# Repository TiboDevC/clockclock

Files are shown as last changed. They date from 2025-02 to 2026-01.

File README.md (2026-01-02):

# ClockClock - 48 Stepper Motors Kinetic Clock

Personal project of a kinetic clock inspired by [Humans Since 1982](https://www.humanssince1982.com/), using 48 stepper
motors to display time in an artistic and dynamic way.

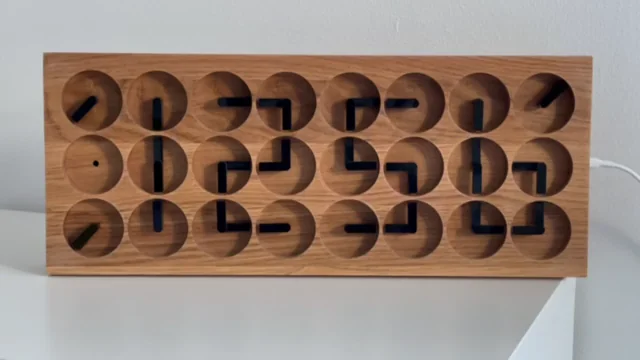
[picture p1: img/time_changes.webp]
Clock front


## Table of Contents

- [Project Overview](#project-overview)
- [Technical Architecture](#technical-architecture)
- [Hardware](#hardware)
- [Firmware](#firmware)
- [Build and Flash](#build-and-flash)
- [Configuration](#configuration)
- [Schematics and Documentation](#schematics-and-documentation)

---

## Project Overview

### Goals

This project aims to create a kinetic clock with the following constraints:

1. **Simplicity**: Use a single microcontroller (ESP32-C3) to control all 48 motors, unlike similar projects that use
   multiple MCUs
2. **Time Accuracy**: Always accurate clock without permanent internet connection thanks to DCF77 receiver
3. **Compact Size**: Target dimensions around 100 cm length
4. **Cost-Effective**: Reasonable budget using BKA30D-R5 motors at ~4€/piece

### Specifications

- **48 stepper motors** individually controlled
- **Display**: 4 digits (HH:MM) with 12 motors per digit
- **Angular Resolution**: 4320 steps/revolution (12 steps/degree)
- **Power Consumption**: ~960 mA @ 5V (20mA/motor)
- **Time Synchronization**: DCF77 (European long-range radio signal)

---

## Technical Architecture

### Overview

The ClockClock architecture is built around a highly efficient, centralized control system that manages all 48 stepper
motors from a single ESP32-C3 microcontroller. This approach contrasts with typical multi-motor projects that require
multiple microcontrollers or complex distributed systems.

#### Control Chain

```
ESP32-C3 → TPIC6C595 Shift Registers (×12) → VID6606 Motor Drivers (×12) → BKA30D-R5 Motors (×48)
   ↓                    ↓                              ↓                           ↓
 3 GPIO              96 bits                    2 signals per motor         2 bits per motor
  pins            (SPI @ 10MHz)                  (STEP + DIR)              (individual control)
```

#### Key Design Principles

1. **Minimal GPIO Usage**: The entire system uses only 3 GPIO pins (MOSI, SCK, SS) thanks to the shift register cascade.
   This leaves the ESP32-C3's remaining pins available for other peripherals (I2C for RTC, buttons, encoder, etc.).

2. **Serial-to-Parallel Conversion**: The 12 cascaded TPIC6C595 shift registers convert the serial SPI data stream into
   96 parallel outputs. Each motor requires 2 control bits (STEP and DIR), allowing precise control of all 48 motors
   simultaneously.

3. **Hierarchical Organization**:
    - **1 ESP32-C3**: Single point of control and decision-making
    - **12 Shift Registers**: Each controlling 4 motors (8 bits per register)
    - **12 VID6606 Drivers**: Each driving 4 motors independently
    - **48 Motors**: Organized in 4 groups of 12 (one per digit displayed)

4. **Data Flow Pipeline**:
   ```
   Time/Animation Logic → Motor Position Calculation → SPI Data Preparation → 
   Hardware SPI Transfer (10µs) → Parallel Latch → Simultaneous Motor Update
   ```

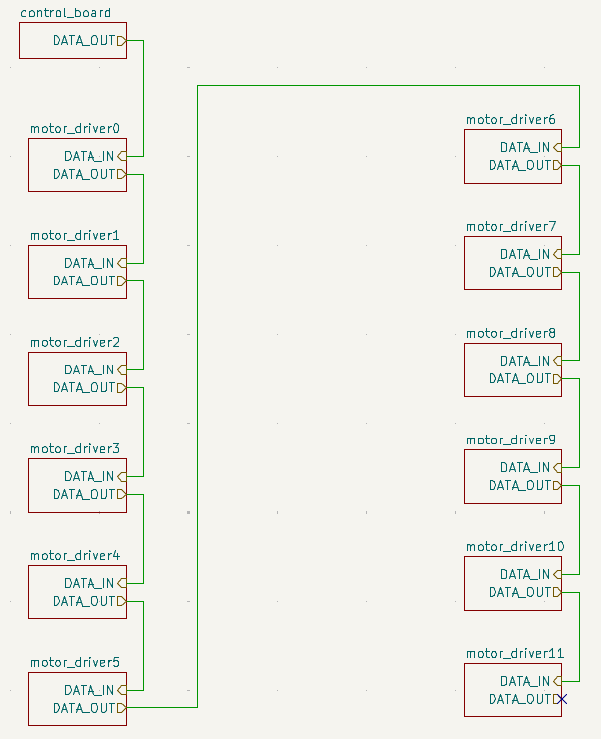
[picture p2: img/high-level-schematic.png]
High Level Schematic

*All motor blocks are linked together*

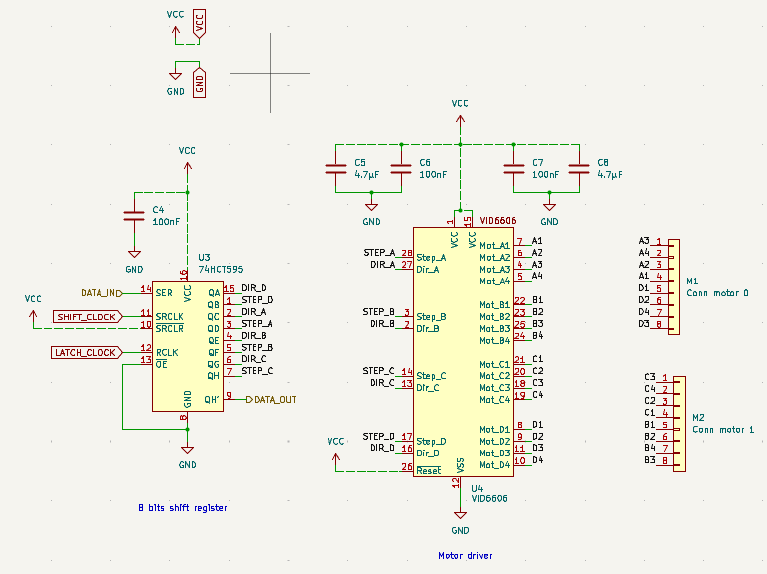
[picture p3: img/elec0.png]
Electronic Architecture

*A motor block*

### Motor Control

#### BKA30D-R5 Stepper Motors

Features:

- **Type**: Bipolar stepper motor
- **Current**: 20 mA per motor
- **Resolution**: 360° continuous rotation
- **Torque**: Suitable for lightweight hands (acrylic)

<p>
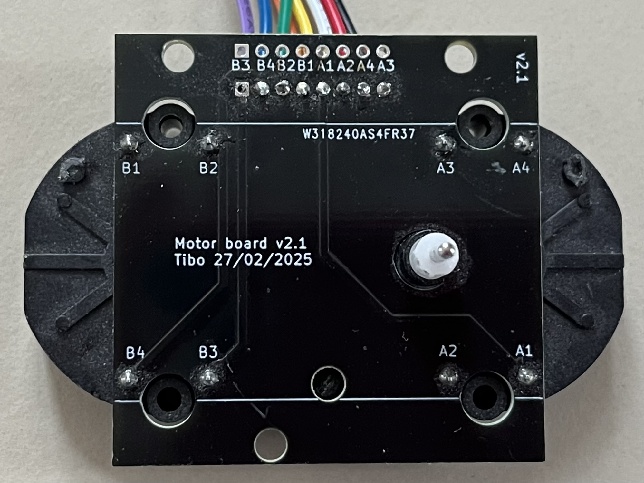
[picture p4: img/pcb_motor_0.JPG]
Motor
  
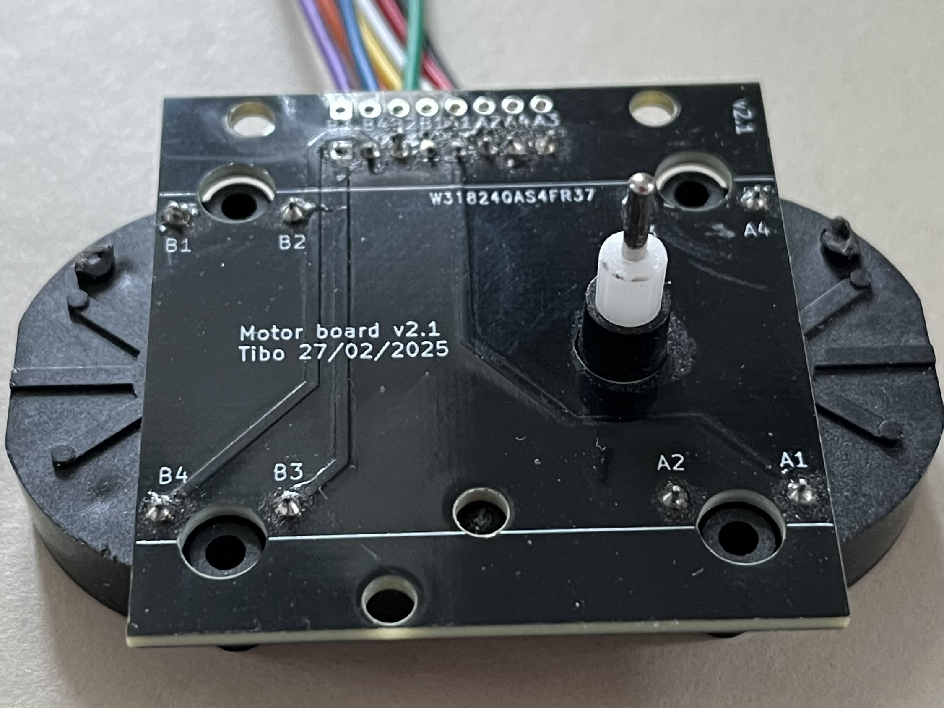
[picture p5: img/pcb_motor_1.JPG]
Motor
  

<em>The motor itself with its PCB to connect to the motor driver</em>
</p>

#### VID6606 Drivers

Each VID6606 driver (or equivalent AX1201728SG/STI6606z) can control **4 motors** with only 2 signals per motor:

- **STEP**: Step signal (rising edge = one step)
- **DIR**: Direction (HIGH/LOW)

<p>
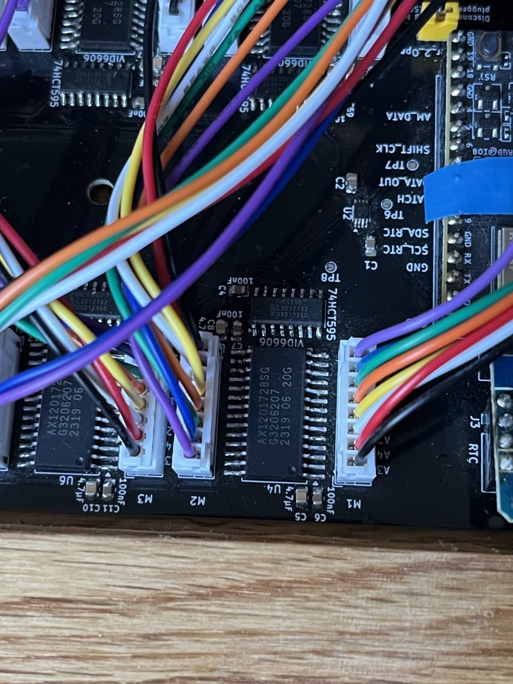
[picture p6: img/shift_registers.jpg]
  

<em>The AX1201728SG driver is connected to 4 motors (the two connectors on its right and left). On top, the shift
register</em>
</p>

#### TPIC6C595 Shift Registers

- **Quantity**: 12 x 8-bit registers in cascade
- **Total**: 96 bits of control for 48 motors (2 bits/motor)
- **Communication**: Hardware SPI interface from ESP32-C3
- **Clock Speed**: 10 MHz
- **Data Transfer**: 12 bytes (96 bits) in approximately 10 µs
- **Signals**:
    - **MOSI** (Data Out): Serial data to first register
    - **SCK** (Shift Clock): Shift clock at 10 MHz
    - **SS** (Latch Clock): Synchronous output latch

**Key Advantages**:

1. **Hardware SPI Optimization**: Using the ESP32-C3's hardware SPI peripheral instead of bit-banging provides
   significant performance improvement. The 10 MHz clock allows extremely fast data transfer of all 12 bytes in
   approximately 10 microseconds.
2. **Perfect Synchronization**: The latch mechanism ensures all 48 motors receive their new commands simultaneously in a
   single atomic operation. There is no timing skew between motors - they all update at exactly the same moment when the
   latch signal is triggered.
3. **Monolithic Control**: This architecture provides a single point of control with zero concurrency issues. All motor
   states are managed centrally by the ESP32-C3, eliminating the complexity and synchronization challenges found in
   distributed control systems using multiple microcontrollers.
4. **Deterministic Timing**: The fast SPI transfer combined with the synchronous latch ensures predictable, jitter-free
   motor updates, critical for smooth visual animations.

### Time Synchronization

#### DS3231 RTC Module

- **Accuracy**: ±2 ppm (±1 minute/year)
- **Interface**: I2C
- **Battery**: CR2032 backup for timekeeping

#### DCF77 Receiver

- **Module**: CANADUINO DCF77 Radio Clock Receiver Kit V2
- **Frequency**: 77.5 kHz (transmitter in Mainflingen, Germany)
- **Range**: ~2000 km in optimal conditions
- **Accuracy**: Atomic clock synchronization
- **Function**: Automatic DS3231 recalibration

#### DST (Daylight Saving Time) Management

The firmware implements European rules:

- **Summer Time Start**: Last Sunday of March at 2:00 → 3:00 (UTC+2)
- **Winter Time Start**: Last Sunday of October at 3:00 → 2:00 (UTC+1)
- **Automatic Calculation**: Zeller's algorithm to determine Sundays

---

## Hardware

### Main Board

**Files**: `elec/clockclock_main/` → [PDF Schematic](elec/clockclock_main/output/clockclock_main.pdf)

<p>
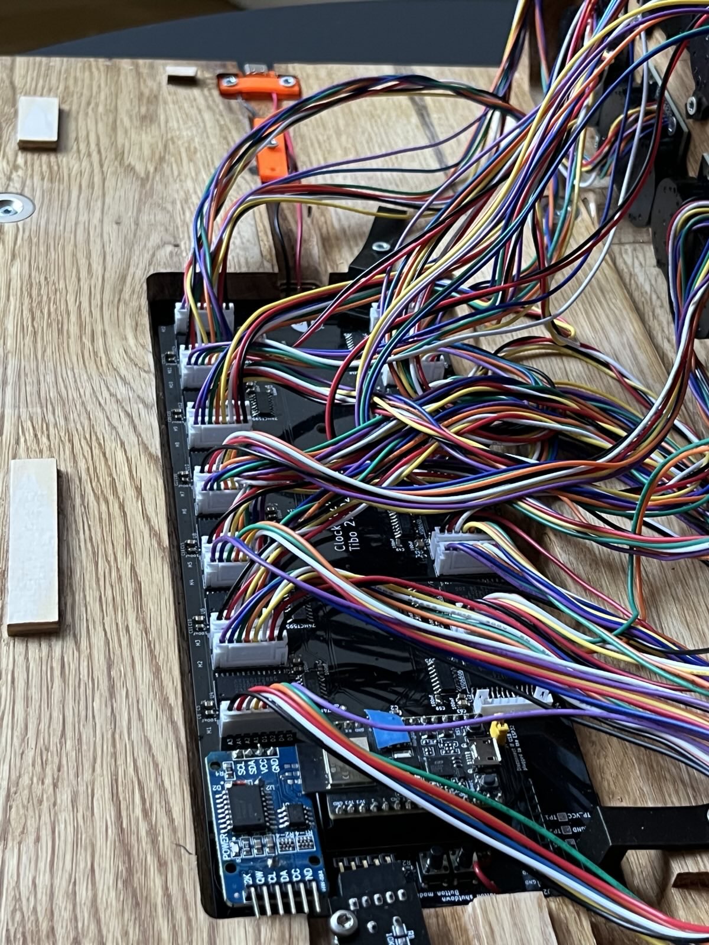
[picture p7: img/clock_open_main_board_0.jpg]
Main board
  
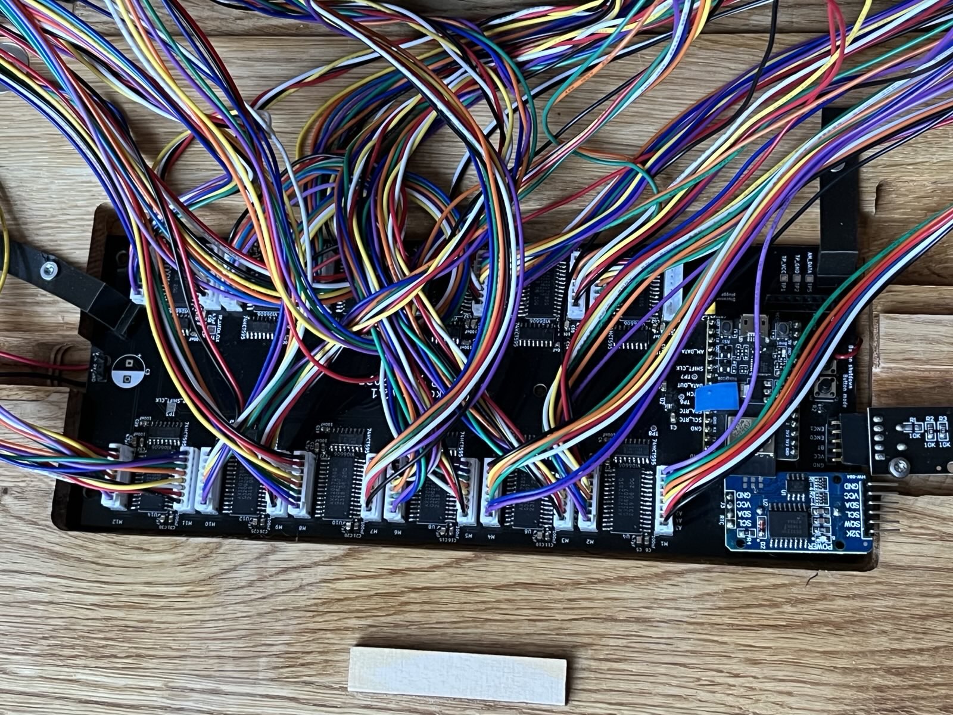
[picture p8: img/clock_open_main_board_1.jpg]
Main board
  

<em>Main board fully wired</em>
</p>

<p>
  Clock starts

<em>Clock starts</em>
</p>

#### Main Components

| Component | Reference | Quantity | Function |
|---|---|---|---|
| Microcontroller | ESP32-C3-DevKitM-1 | 1 | Central control (RISC-V) |
| Shift Registers | TPIC6C595 | 12 | Output expansion |
| Motor Drivers | VID6606 / AX1201728SG | 12 | 4 motors per driver |
| RTC | DS3231 | 1 | Real-time clock |
| Radio Receiver  | DCF77 CANADUINO | 1 | Atomic sync |

#### User Interface

**Buttons**:

- **PIN 0**: Rotary encoder button
- **PIN 1**: Mode (short = config, long = calibration)
- **PIN 10**: Shutdown (long press)

**Rotary Encoder**:

- **PIN 2**: Encoder A (interrupt)
- **PIN 3**: Encoder B (interrupt)

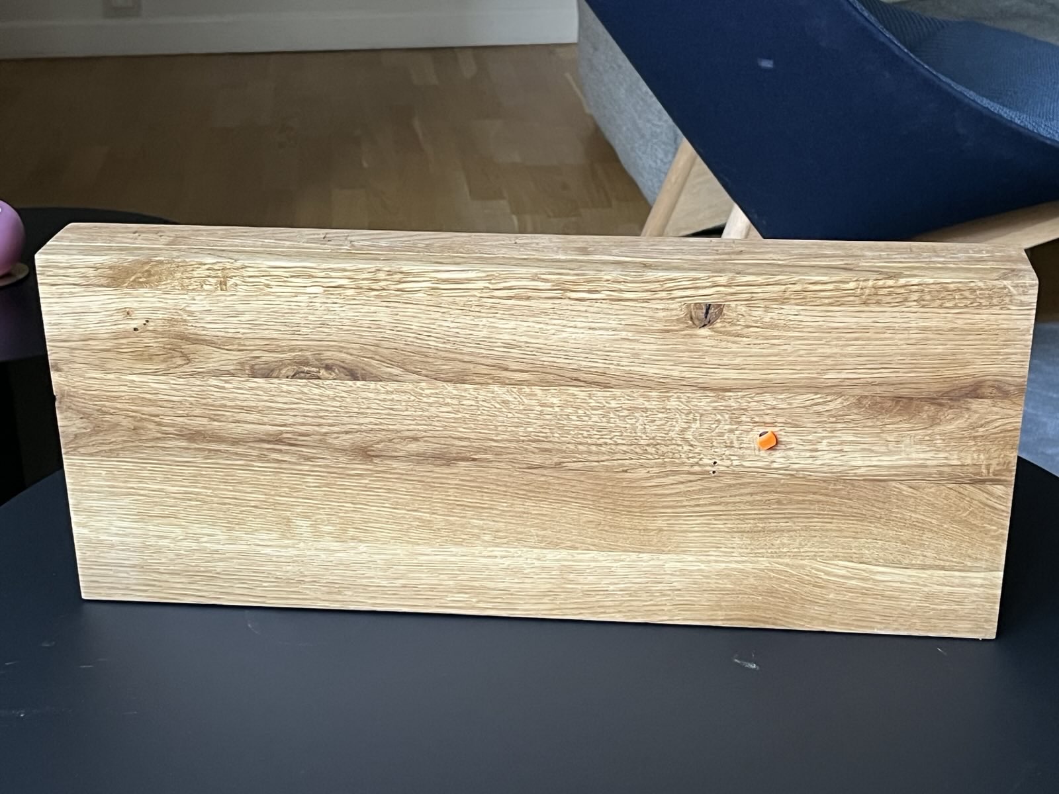
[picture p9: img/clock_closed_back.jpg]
Back of the clock

*Only one button is connected (the orange button here), and it is used to enter the "shutdown" mode*

### Motor Boards

**Files**: `elec/clokclock_stepper/` → [PDF Schematic](elec/clokclock_stepper/output/clokclock_stepper.pdf)

Each board is very simple and connects a BKA30D-R5 motor to its VID6606 driver.

**Total**: 24 identical motor boards

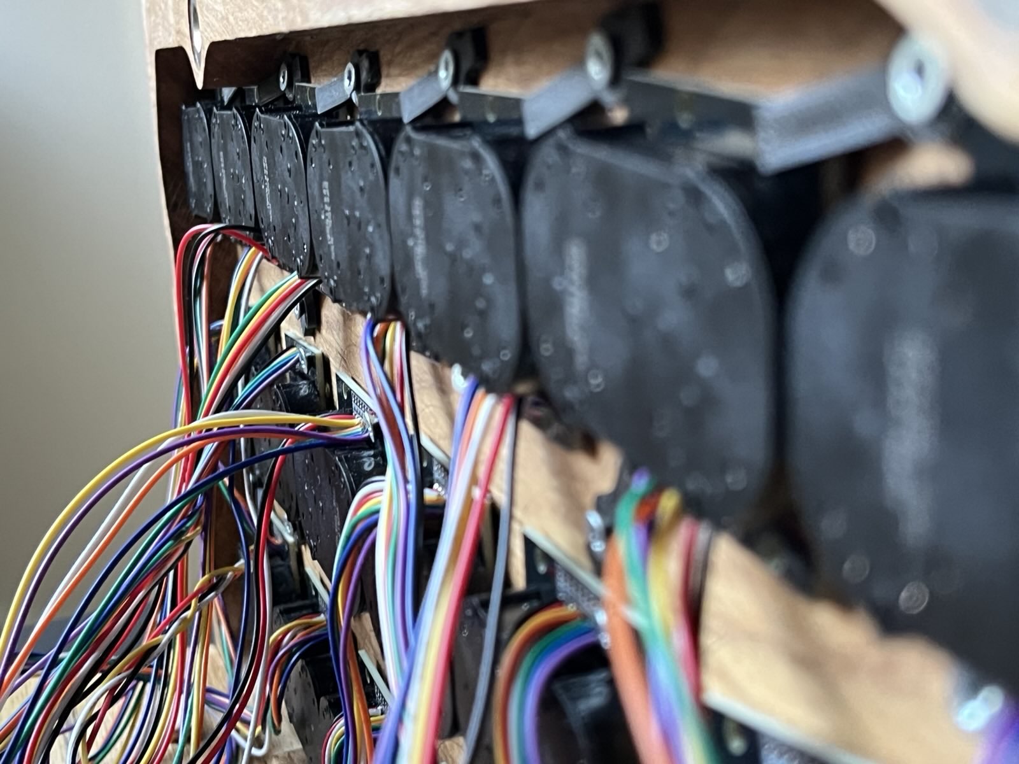
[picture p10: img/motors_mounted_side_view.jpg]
Motors mounted

*Row of motors mounted on the main frame*

### Power Supply

- **Source**: Standard USB-C charger
- **Voltage**: 5V DC
- **Current**: Minimum 1.5A recommended
- **Regulation**: Integrated on ESP32-C3-DevKitM-1 (3.3V logic)

### Hands

This is the part that took most of the design time!
I tried many different materials and manufacturing methods before settling on laser-cut acrylic hands.

The challenge is to be able to manufacture hands that can be unmounted/remounted easily and that fit perfectly on the
motor shaft.  
In addition, the hands should be as close together as possible in order to maintain a good viewing angle when looking at
the clock from the side.

<p>
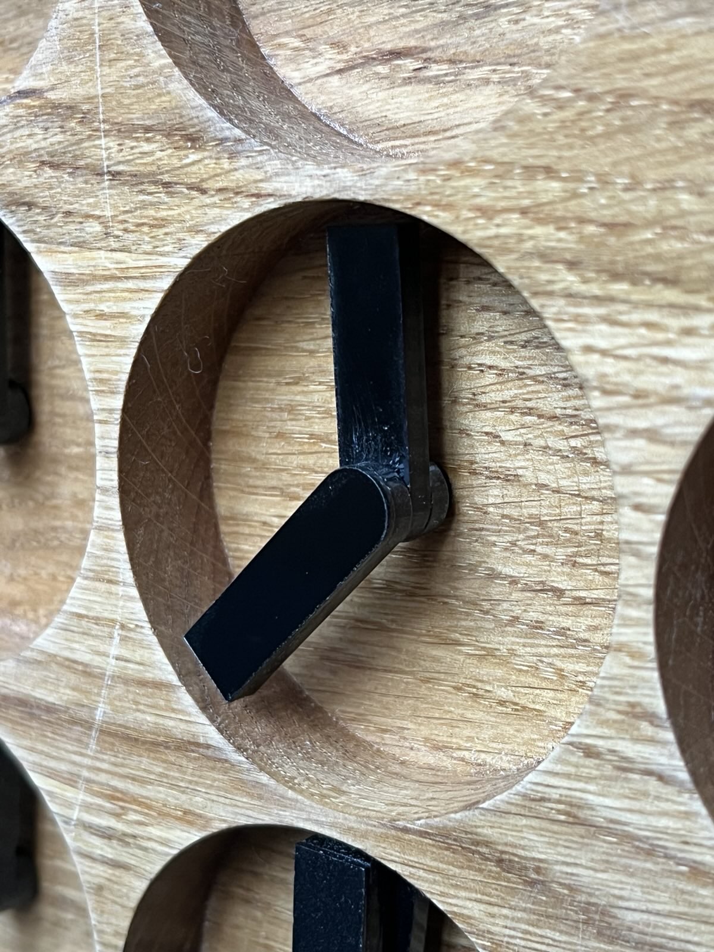
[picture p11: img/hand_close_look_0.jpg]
Hand
  
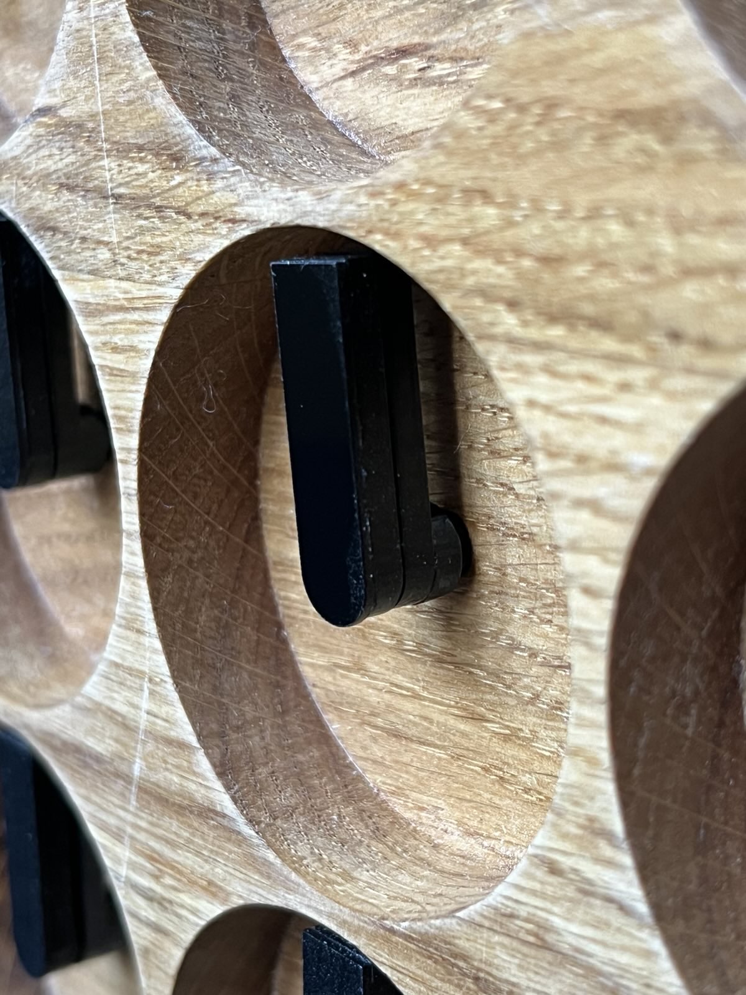
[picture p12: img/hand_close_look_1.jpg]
Hand
  

<em>Mounted hands</em>
</p>

Here is the final solution I adopted:
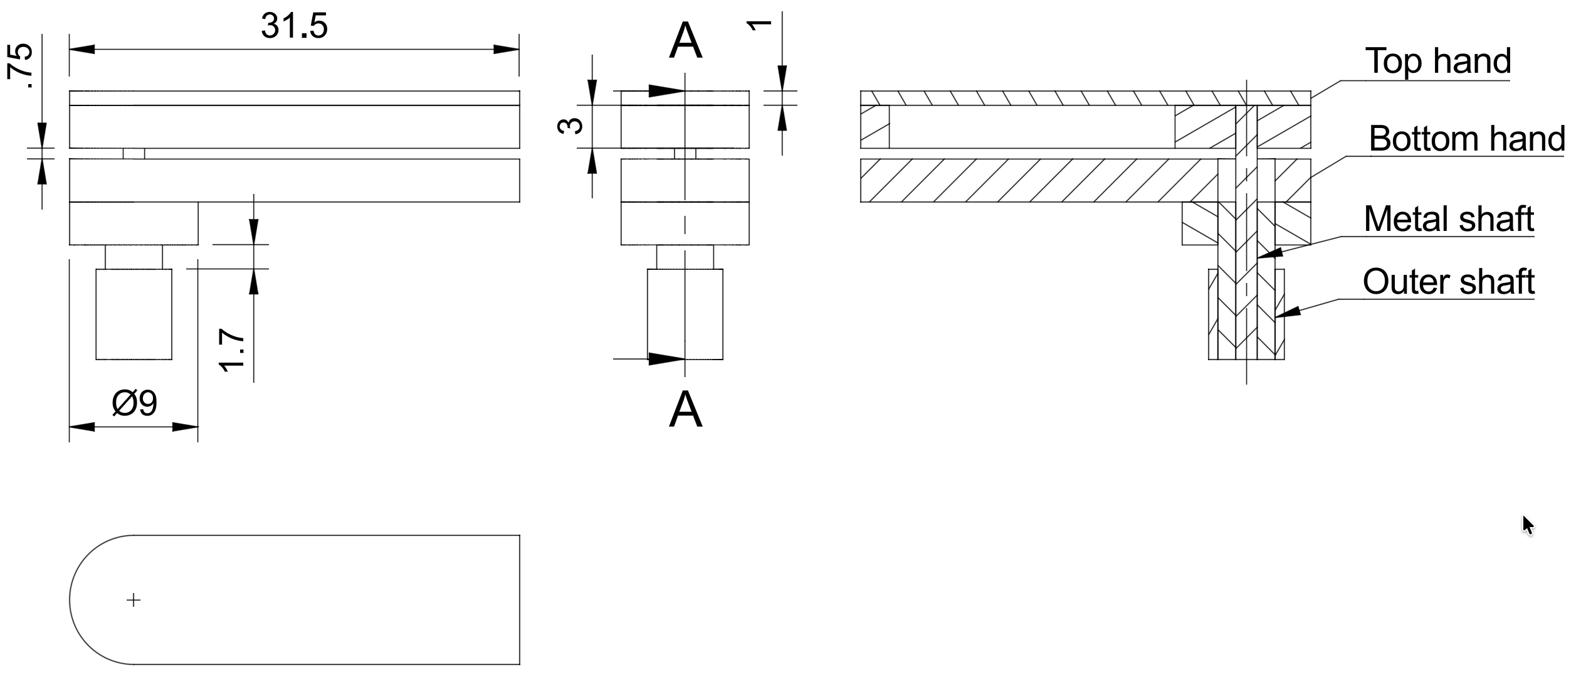
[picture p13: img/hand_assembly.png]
Hands assembly

*Hands assembly*

Both the top and bottom hands are in two acrylic parts glued together.  
The top one as a 1mm acrylic part glued to a 3mm part that fits on the motor shaft.  
The bottom one is a 3mm part glued to a 3mm part that fits on the motor shaft.

---

## Firmware

### Development Environment

- **Framework**: Arduino (PlatformIO)
- **Platform**: Espressif32
- **Language**: C++20 (GNU++2a)
- **IDE**: VSCode + PlatformIO recommended

### Code Structure

```
firmware/
├── platformio.ini          # Project configuration
├── include/
│   └── cfg.hpp            # Global constants (motors count, pins, etc.)
└── src/
    ├── main.cpp           # Entry point
    ├── time_manager.*     # Time management and DST
    ├── ntp_sync.*         # Optional NTP sync (dev only)
    ├── animation/         # Animation system
    │   ├── animation_manager.*
    │   ├── wave_animation.*
    │   └── sync_rotation_animation.*
    ├── button/            # Button and encoder handling
    │   └── button.*
    ├── mode/              # Operating modes
    │   ├── mode.*
    │   ├── calibration.*
    │   └── cfg_time.*
    └── motor/             # Motor control
        ├── motor_motion.* # Mapping and sequences
        ├── motion.*       # Display logic
        ├── shift_register.* # SPI interface
        └── AccelStepper.* # Movement library
```

### Operating Modes

The firmware implements several operation modes:

#### 1. MODE_CLOCK_DISPLAY (default)

- Display current time
- Update every minute
- Execute scheduled animations
- Sync with RTC every 500ms

#### 2. MODE_CLOCK_CONFIG

- Manual time configuration
- Navigation with rotary encoder
- Button validation
- 20s timeout → return to display

#### 3. MODE_CALIB (calibration)

- Access: long press MODE button
- Function: Reset zero position of all motors
- Sequence: rotation to reference position, manual validation, save new origin

#### 4. MODE_SHUTDOWN

- Access: long press SHUTDOWN button
- All motors return to neutral position (0°)
- Power saving mode

### Animation System

The `AnimationManager` enables choreographed animations:

**Available Animations**:

1. **Wave Animation**: Undulating wave across all motors
2. **Sync Rotation**: Synchronized rotation of all motors
3. **Custom**: Possibility to implement new animations

**Triggering**:

- **Scheduled**: At specific times (e.g., every hour)
- **Manual**: Via user interface
- **Transition**: Between digit changes

### Libraries

PlatformIO dependencies:

- `NorthernWidget/DS3231@1.1.2`: RTC interface
- `arduino-libraries/NTPClient@^3.2.1`: Optional NTP sync

---

## Build and Flash

### Prerequisites

```bash
# Install PlatformIO CLI
pip install platformio

# Or via VSCode: Install "PlatformIO IDE" extension
```

### Build

```bash
cd firmware/
pio run
```

### Upload to ESP32-C3

```bash
# Via USB
pio run --target upload

# Serial monitor
pio device monitor
```

### WiFi Configuration (Optional)

To enable NTP sync during development, enable `NTP_WIFI_SYNC` define in `main.cpp` and configure your WiFi credentials.

Note: In production, WiFi is not required thanks to the DCF77 module.

---

## Configuration

### Motor Parameters

Motor speed and acceleration can be adjusted in `firmware/src/motor/motor_motion.cpp`.

### Timezone Configuration

The firmware is configured for Central European Time (CET/CEST) by default. To change timezone, modify the DST
configuration in `main.cpp`.

### Initial Calibration

1. Power on the device
2. **Long press** MODE button → Calibration mode
3. Verify physical alignment of hands
4. Validate with encoder button
5. System saves new zero reference

---

## Schematics and Documentation

### Electronic Design Files

| Document | Path | Format |
|---|---|---|
| Main board schematic  | [`elec/clockclock_main/output/clockclock_main.pdf`](elec/clockclock_main/output/clockclock_main.pdf) | PDF |
| Main board PCB | `elec/clockclock_main/clockclock_main.kicad_pcb` | KiCad  |
| Motor board schematic | [`elec/clokclock_stepper/output/clokclock_stepper.pdf`](elec/clokclock_stepper/output/clokclock_stepper.pdf) | PDF |
| Motor board PCB | `elec/clokclock_stepper/clokclock_stepper.kicad_pcb` | KiCad  |
| Driver test board | `elec/test_board_motor_driver/` | KiCad  |

### Datasheets

All datasheets are available in the [`datasheet/`](datasheet/) folder:

- **Motor**: [BKA30D-R5.webp](datasheet/BKA30D-R5.webp)
- **Driver**: [VID28 user manual](datasheet/VID28%20user%20manual-1.pdf)
- **DCF77**: [CANADUINO_Atomic_Clock_Receiver_Kit_V2.pdf](datasheet/CANADUINO_Atomic_Clock_Receiver_Kit_V2.pdf)

---

## Development Notes

### Debug

The code includes conditional debug flags that can be enabled in respective source files:

- `DEBUG` - General messages
- `DEBUG_MOTION` - Motor control debug
- `DEBUG_TIME_MGMT` - Time management debug
- `DEBUG_ANIMATION` - Animation debug
- `DEBUG_MODE` - Mode debug

### Pre-commit Hooks

Git pre-commit configuration available: `.pre-commit-config.yaml`

```bash
pip install -r requirements.txt
pre-commit install
```

---

## License

This project is open-source. Free to use and modify.

## Acknowledgments

Inspired by the artistic work of [Humans Since 1982](https://www.humanssince1982.com/).

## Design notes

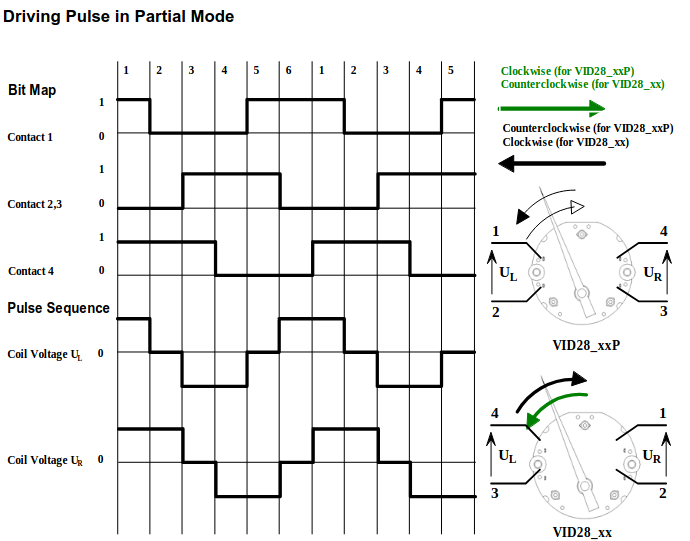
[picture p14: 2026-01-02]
img/BKA30D-R5_sequence.png

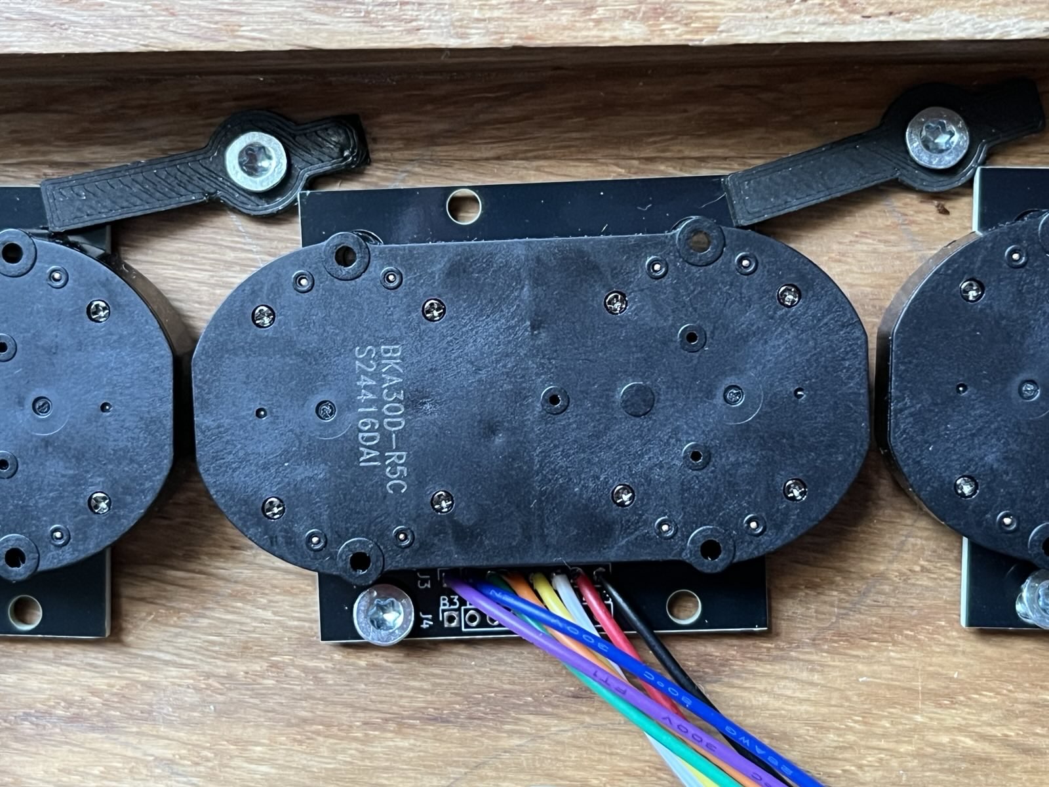
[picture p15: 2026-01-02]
img/motor_mounted.jpg

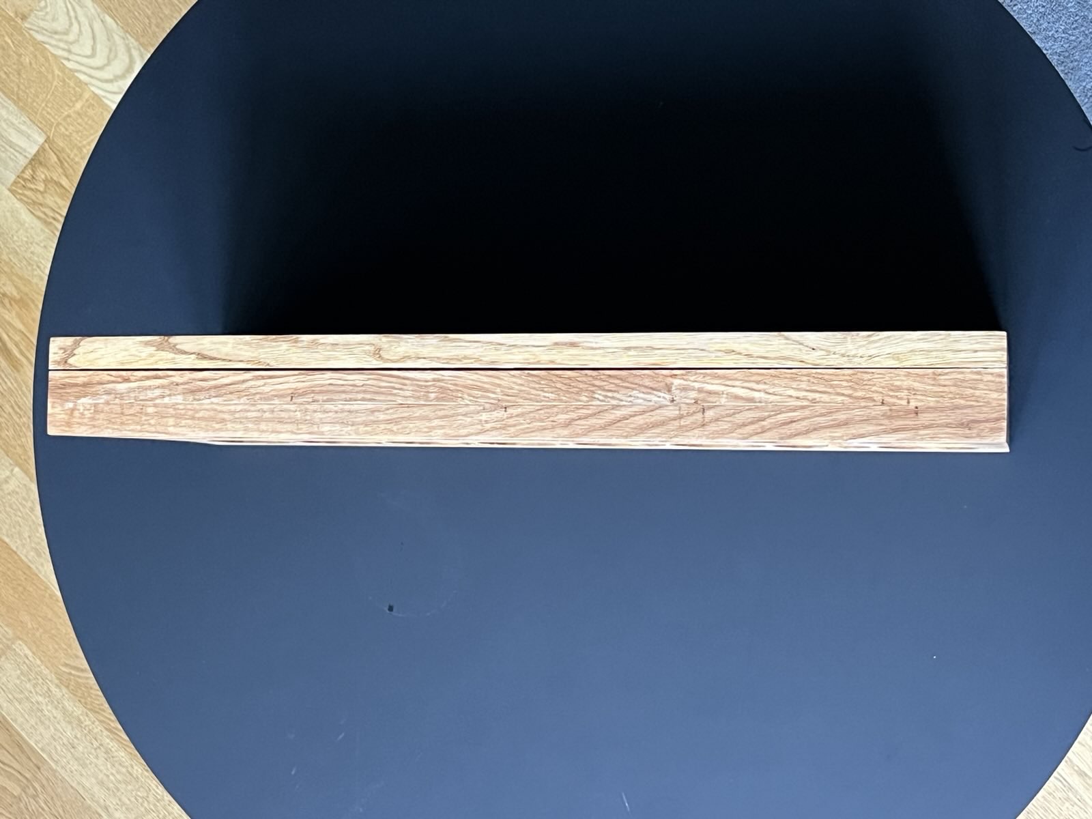
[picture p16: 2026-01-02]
img/clock_closed_top.jpg

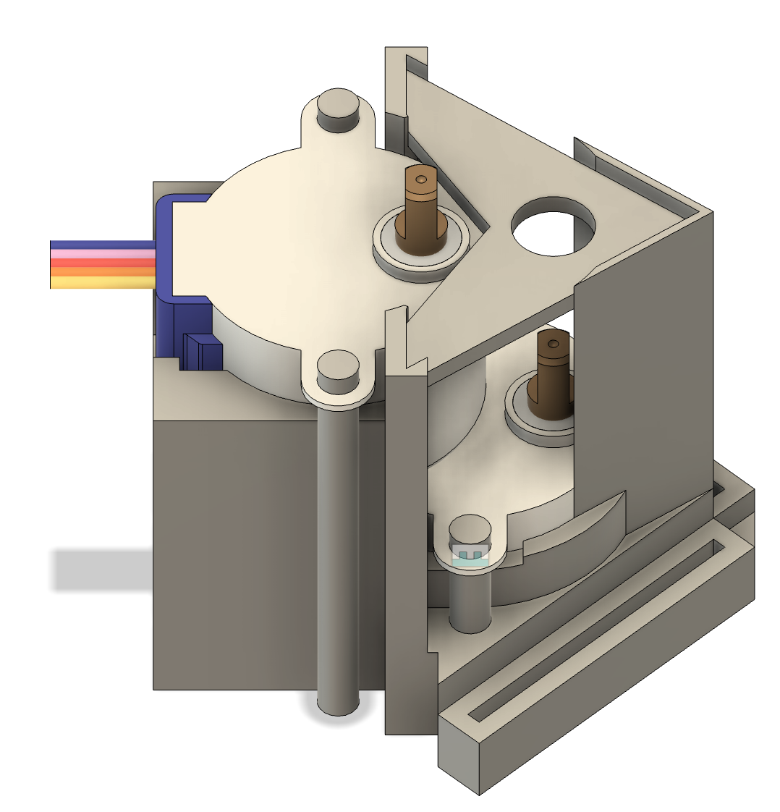
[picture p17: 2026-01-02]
img/motor00000.png

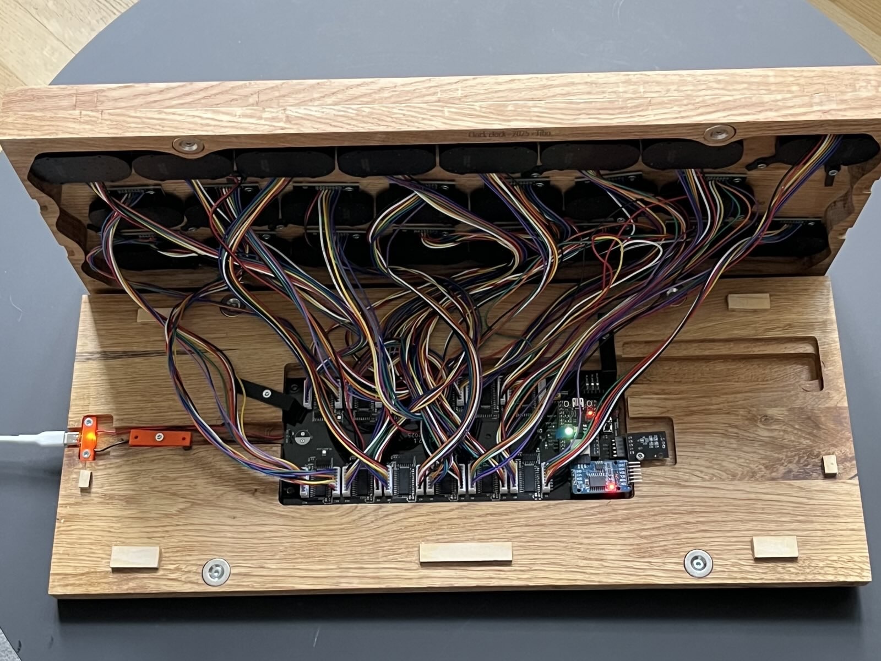
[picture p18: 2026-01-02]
img/clock_open_back.jpg

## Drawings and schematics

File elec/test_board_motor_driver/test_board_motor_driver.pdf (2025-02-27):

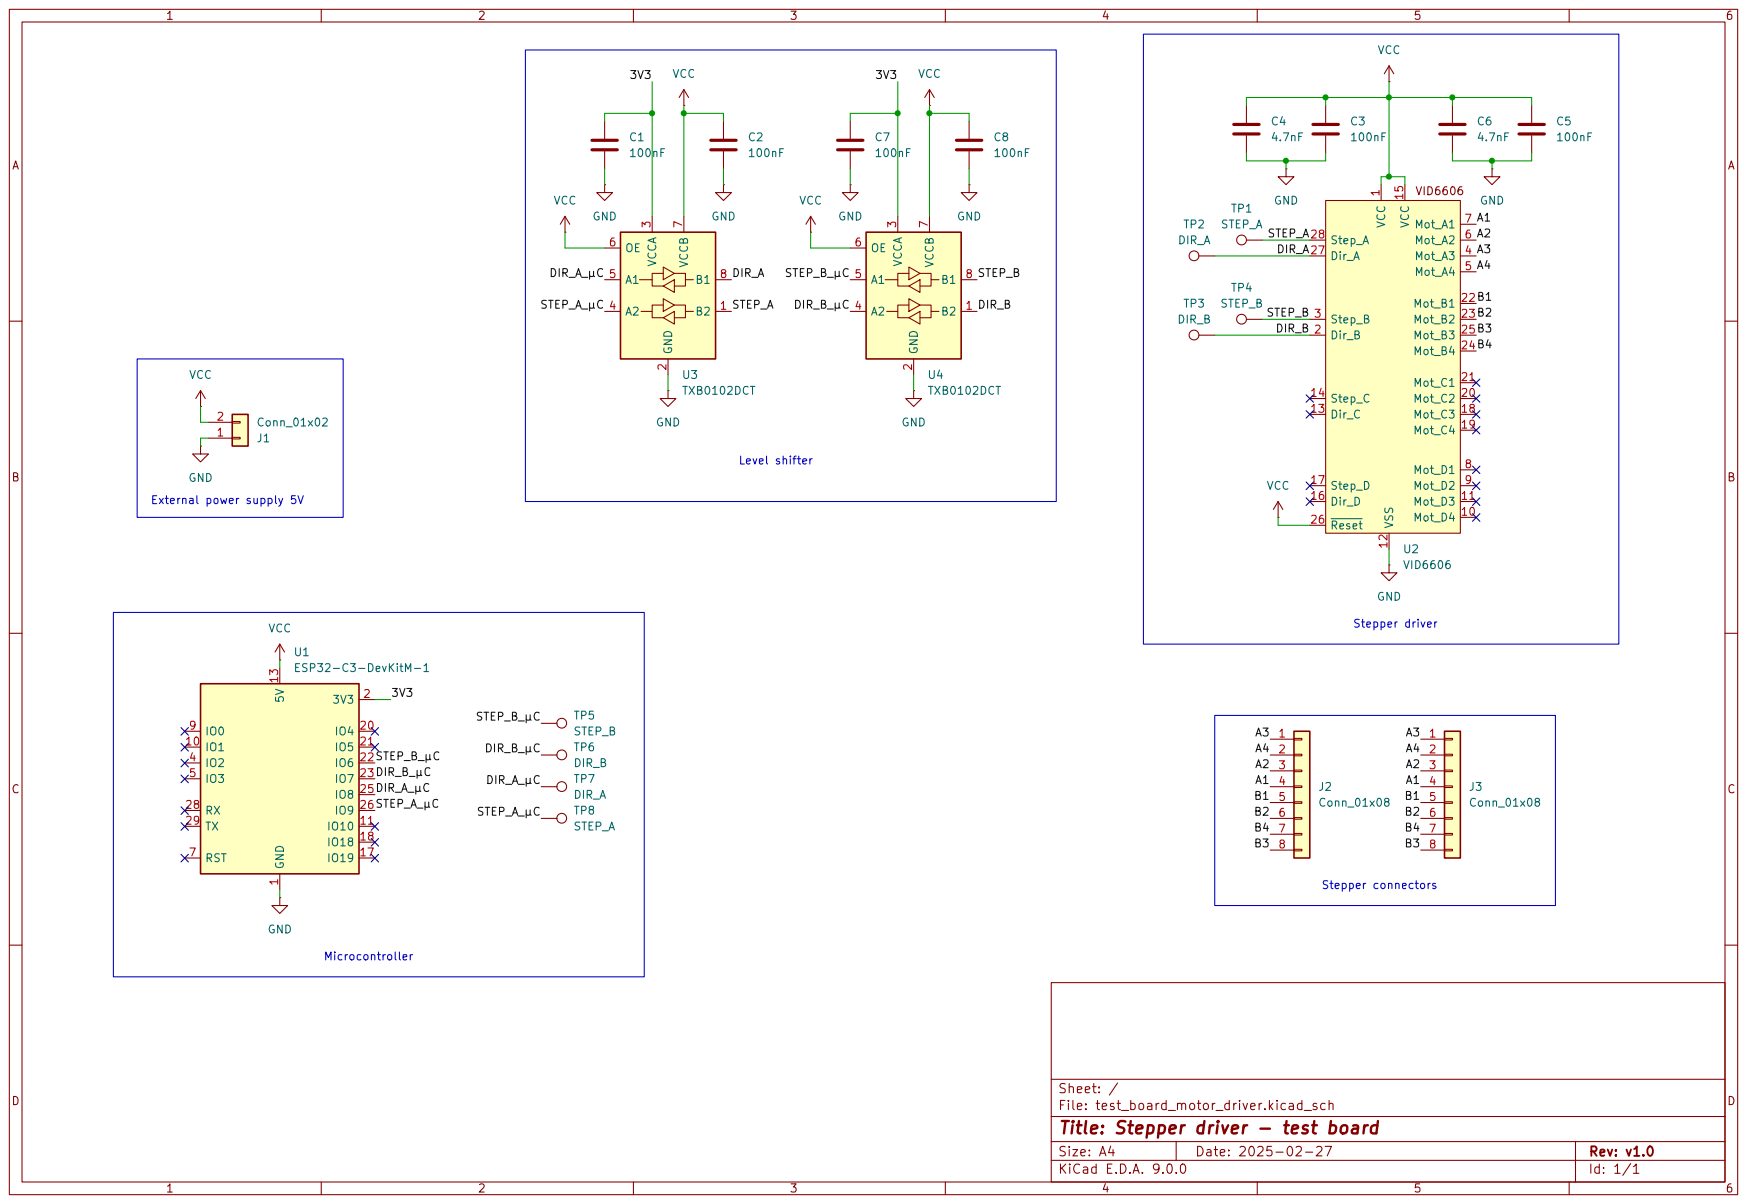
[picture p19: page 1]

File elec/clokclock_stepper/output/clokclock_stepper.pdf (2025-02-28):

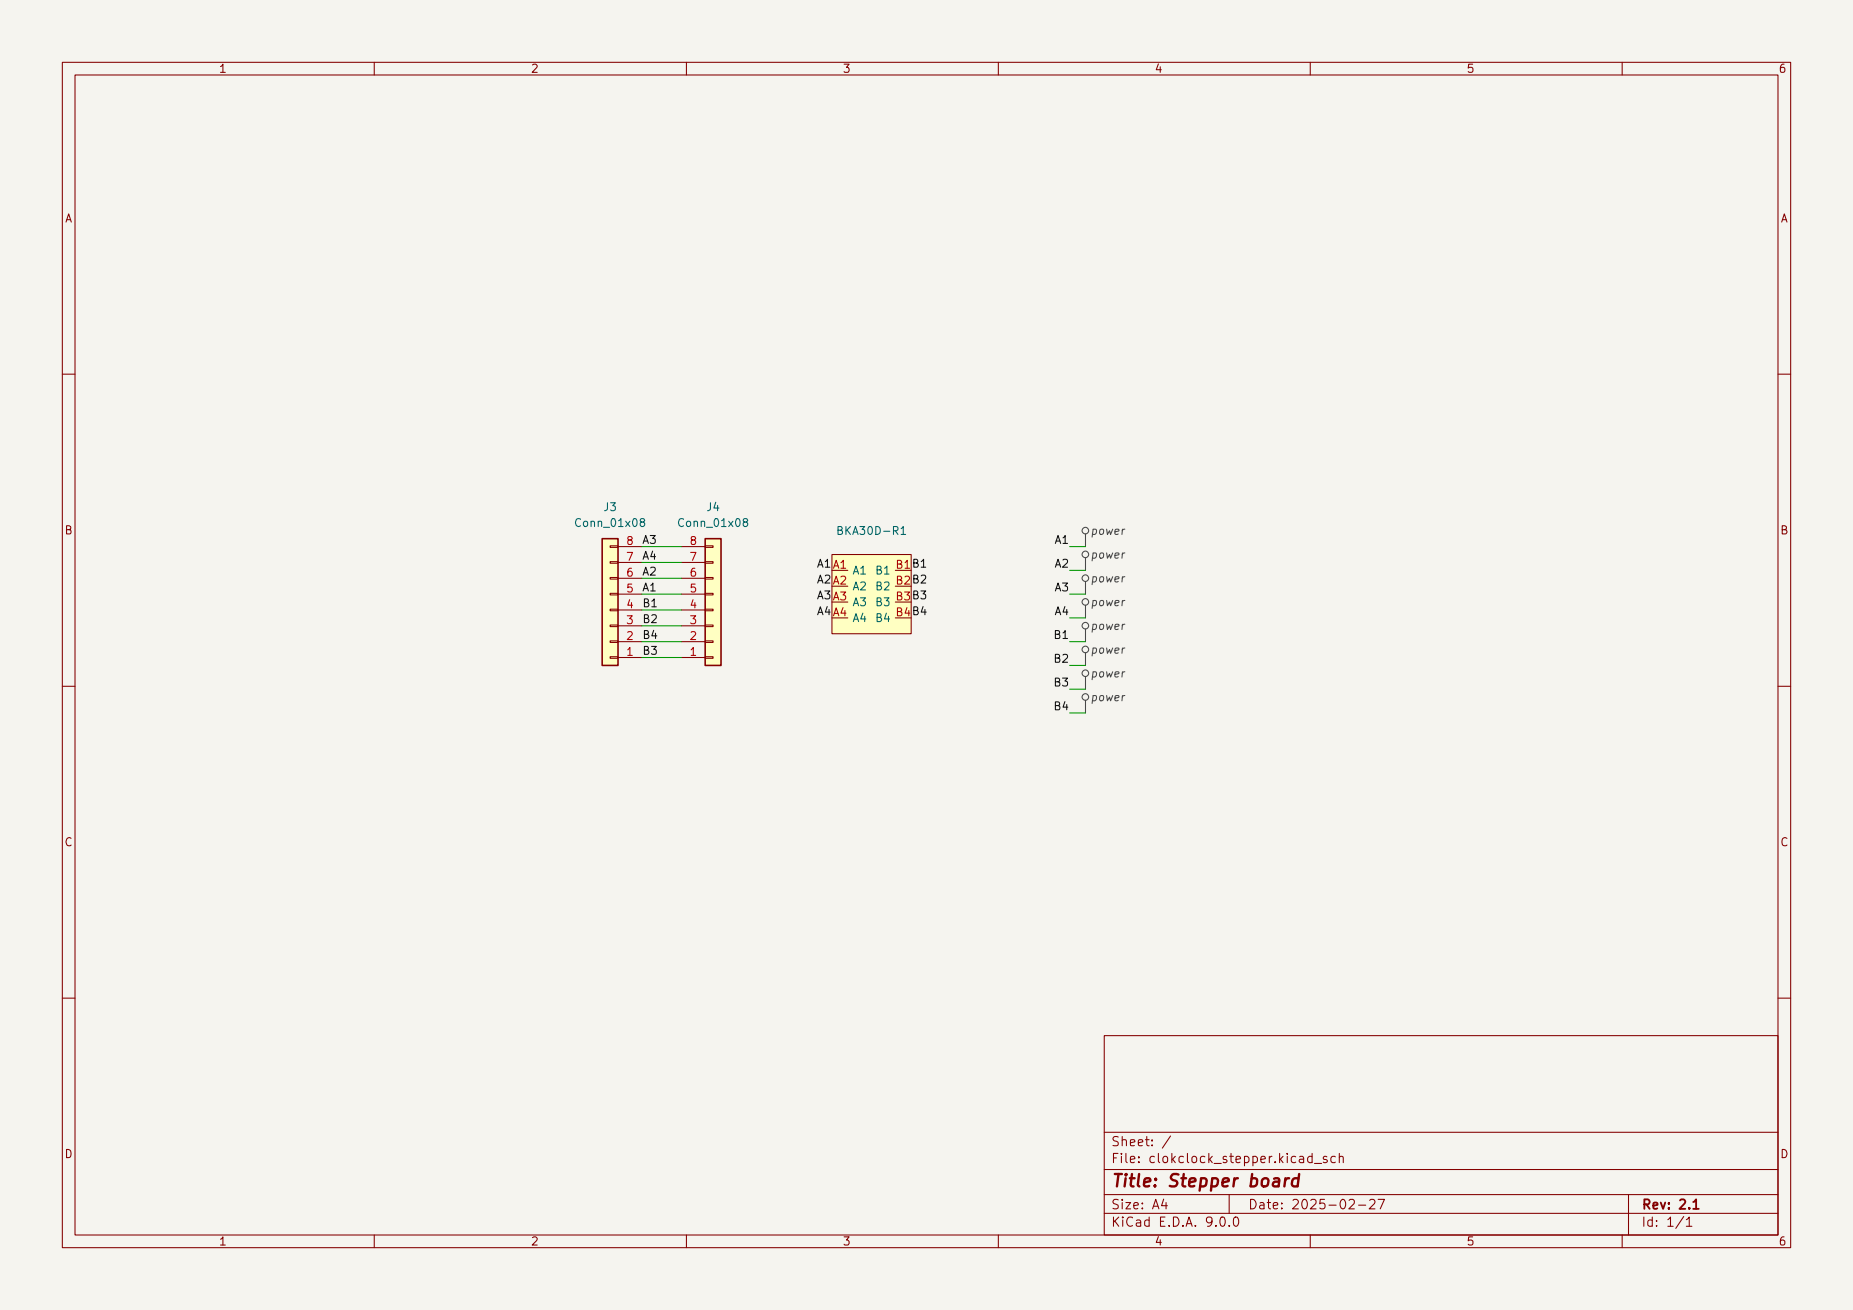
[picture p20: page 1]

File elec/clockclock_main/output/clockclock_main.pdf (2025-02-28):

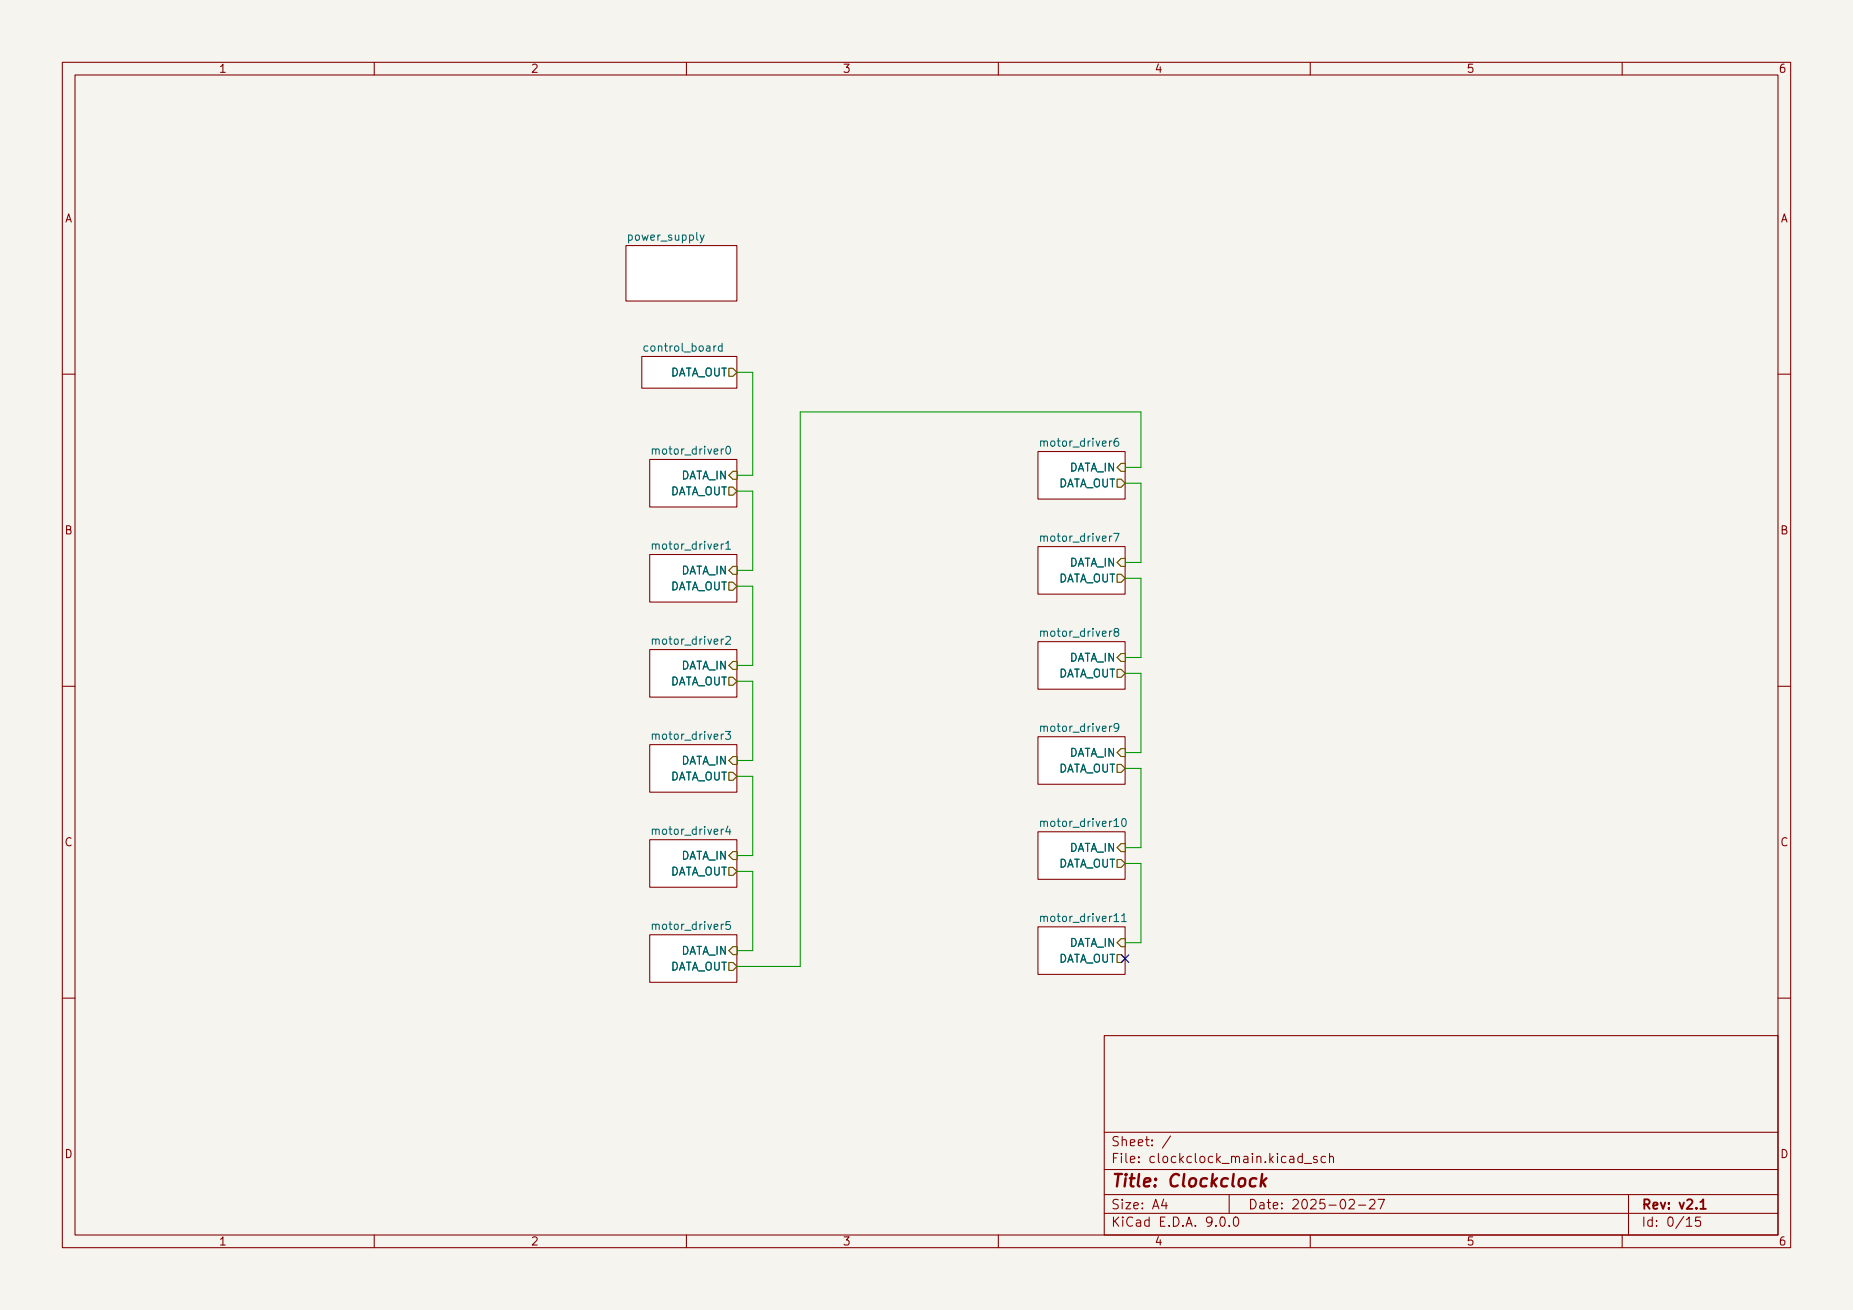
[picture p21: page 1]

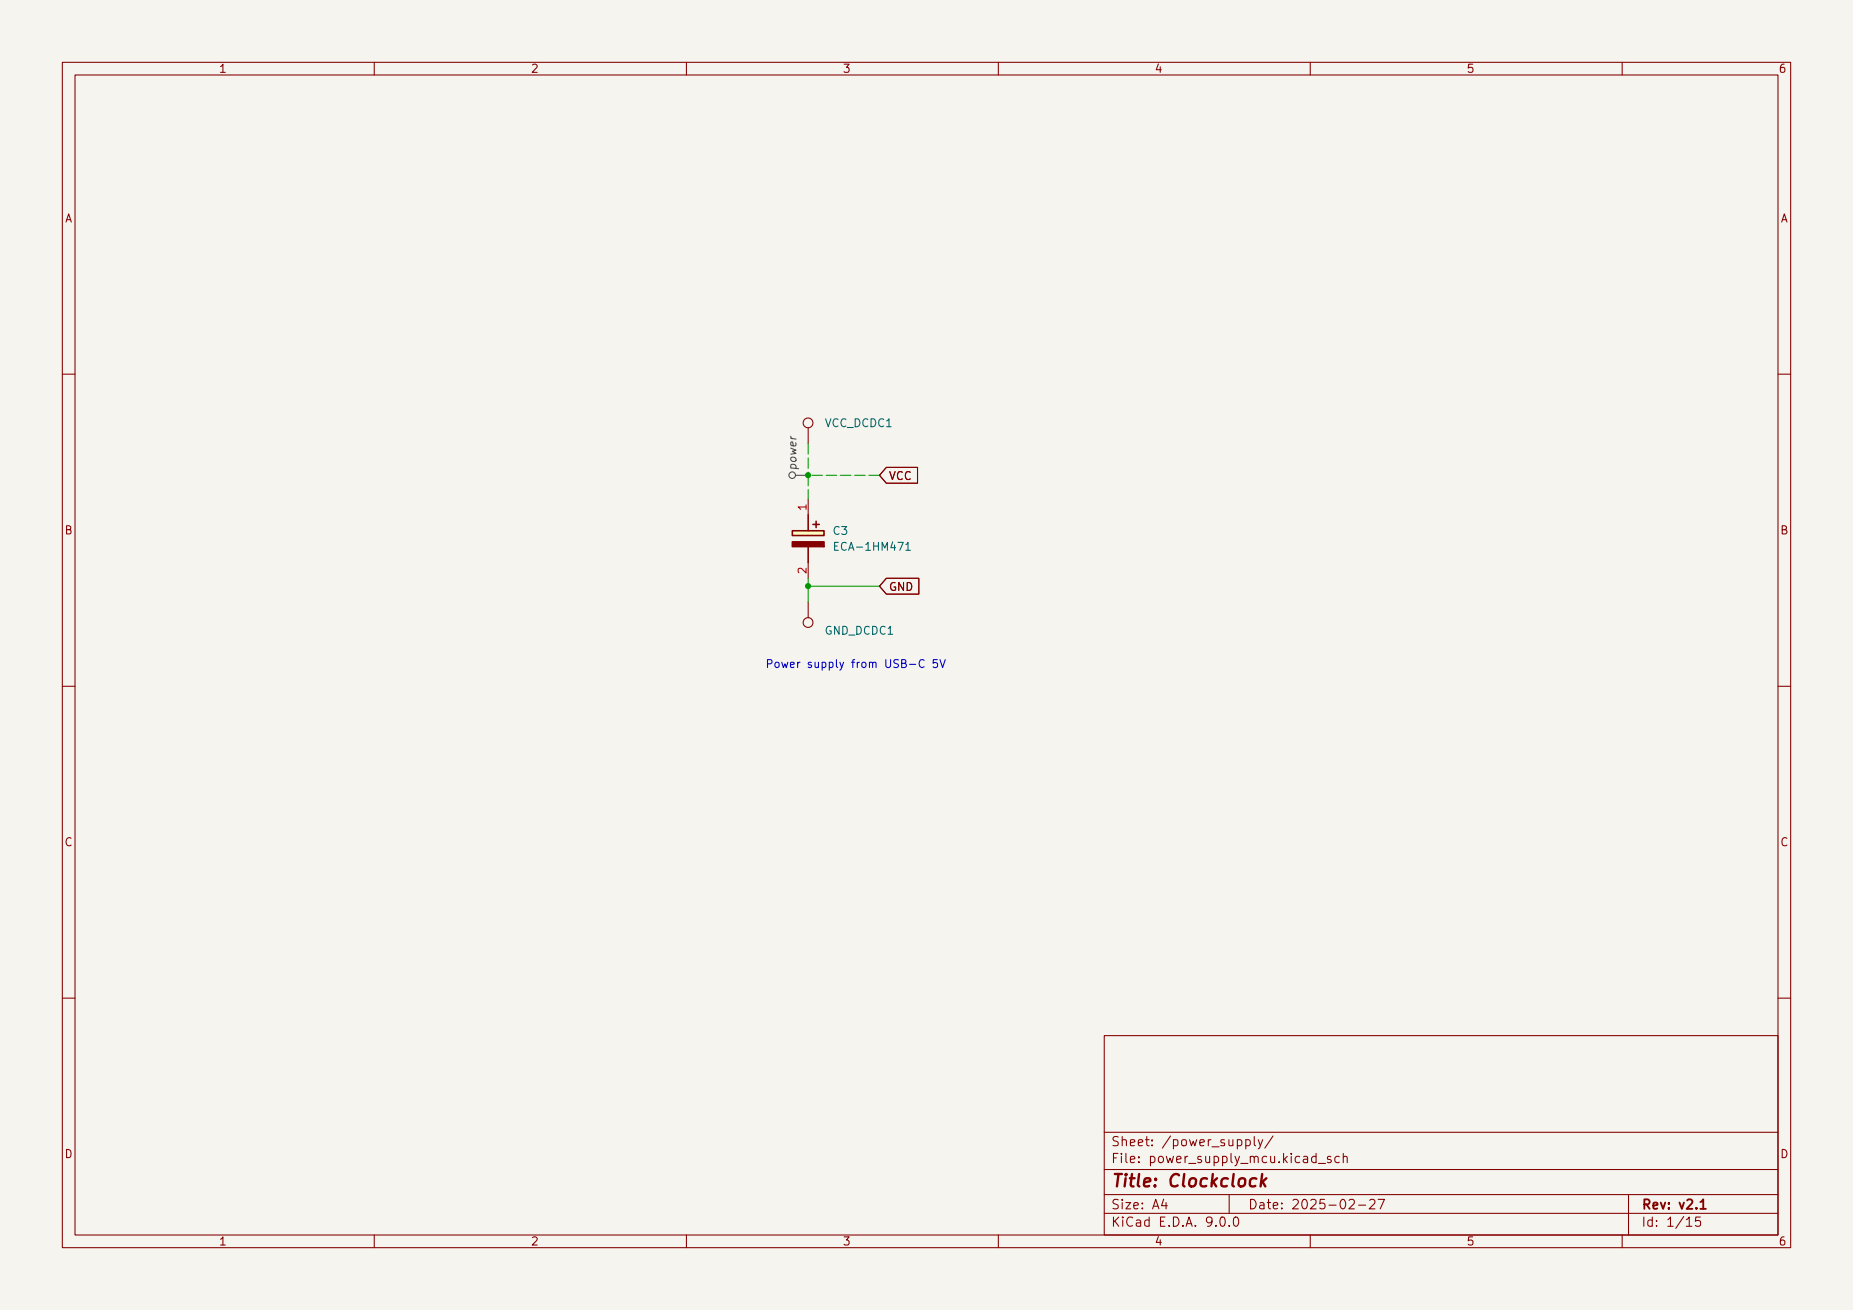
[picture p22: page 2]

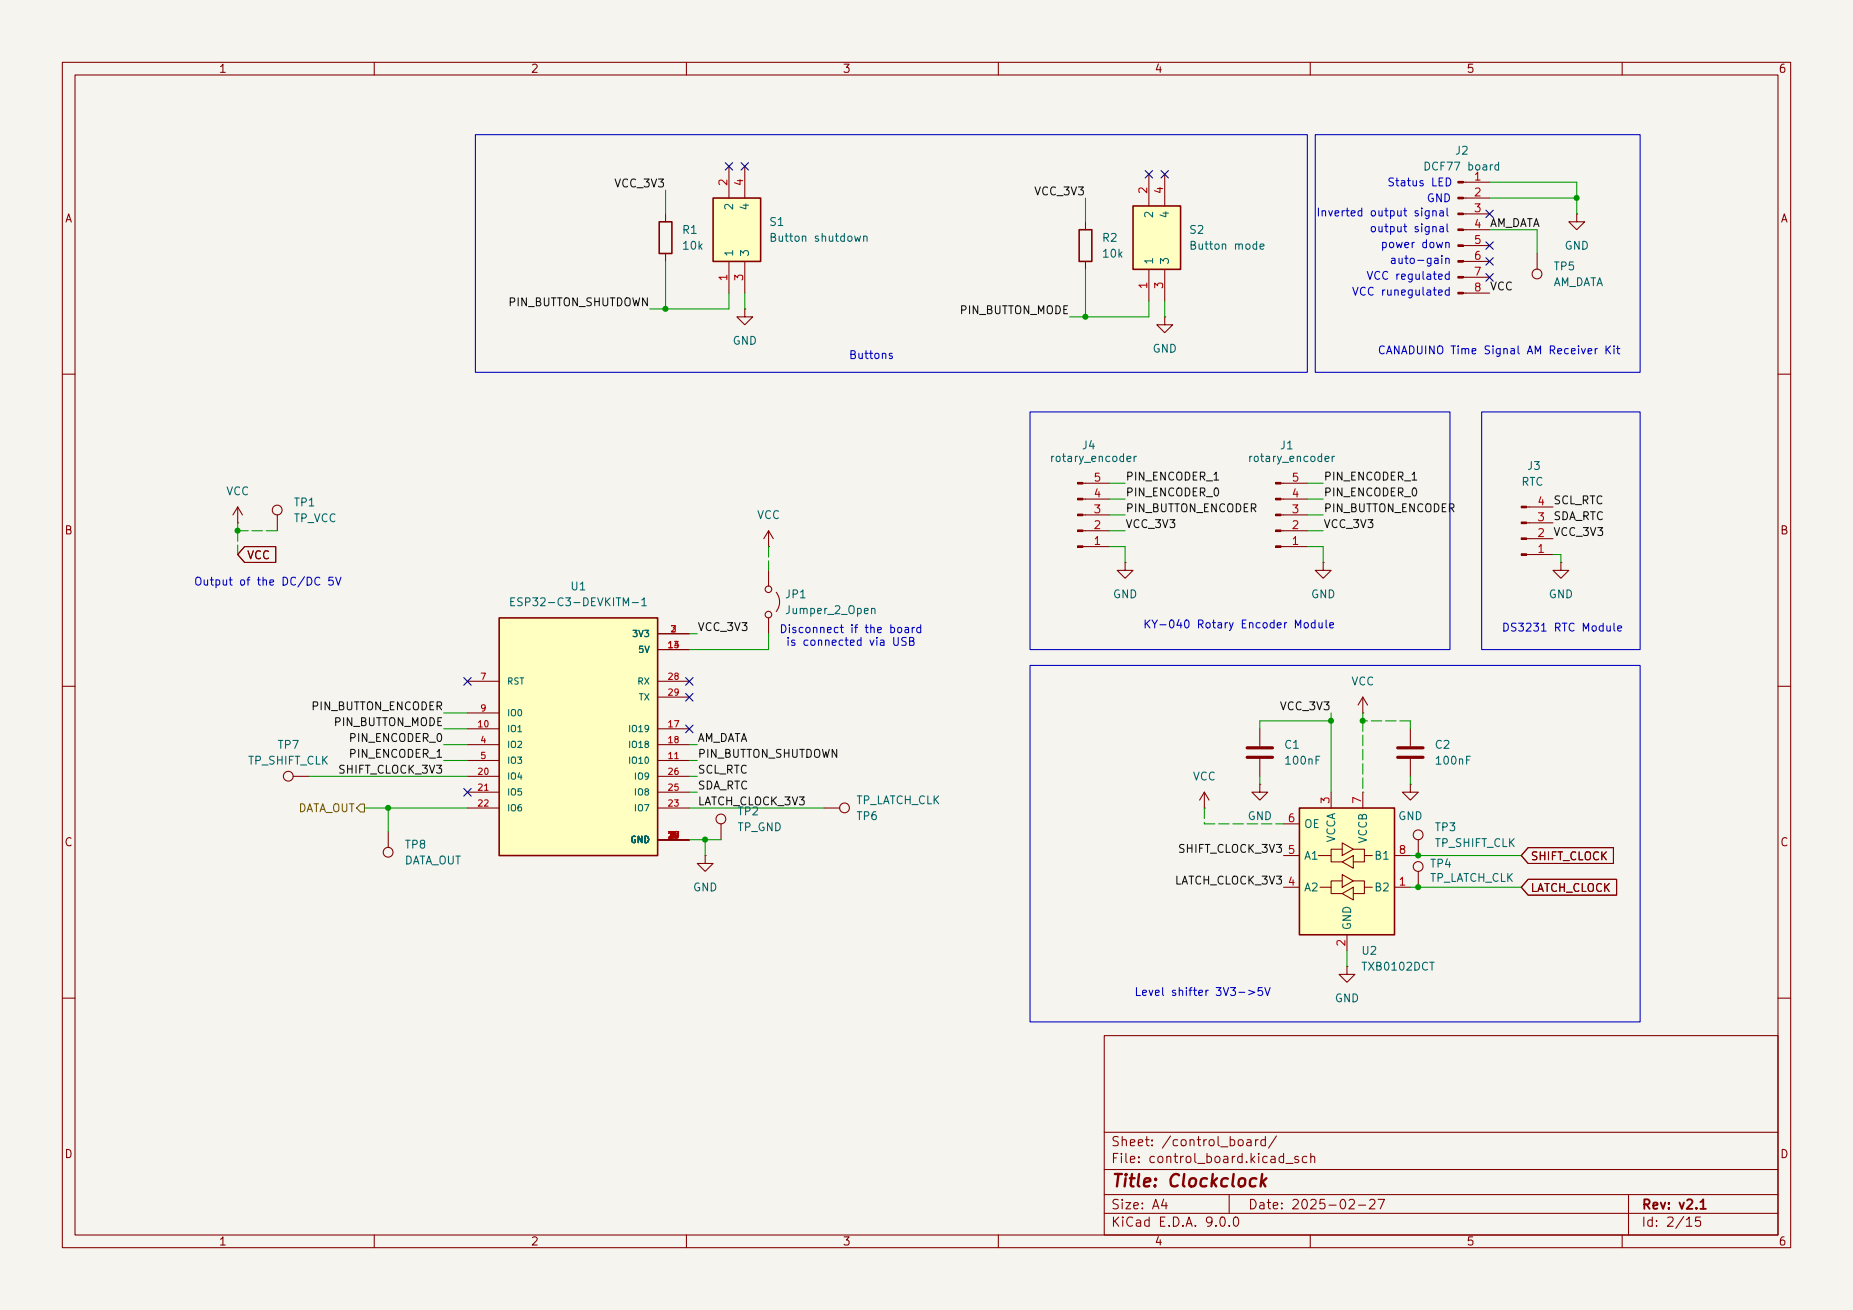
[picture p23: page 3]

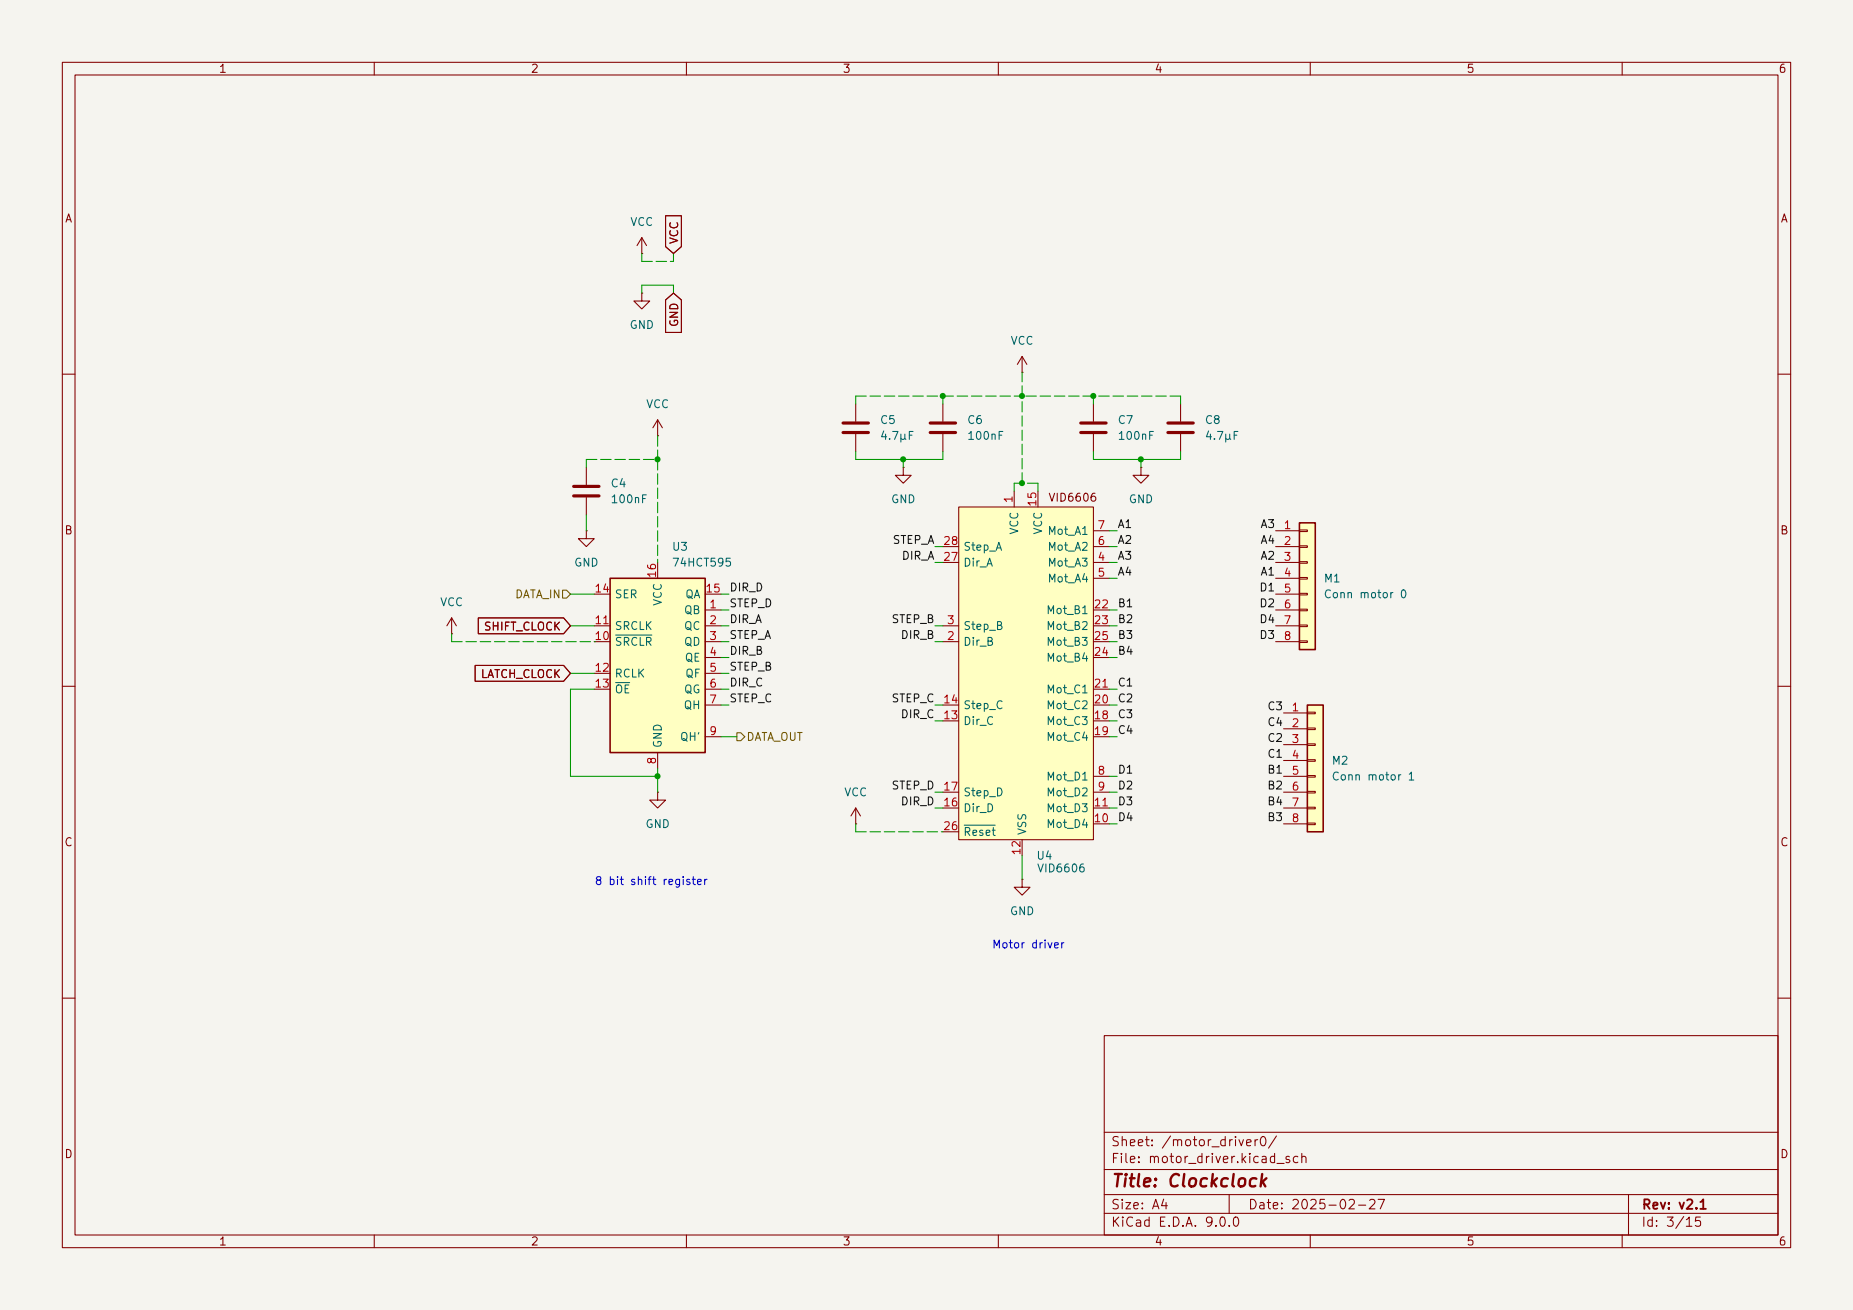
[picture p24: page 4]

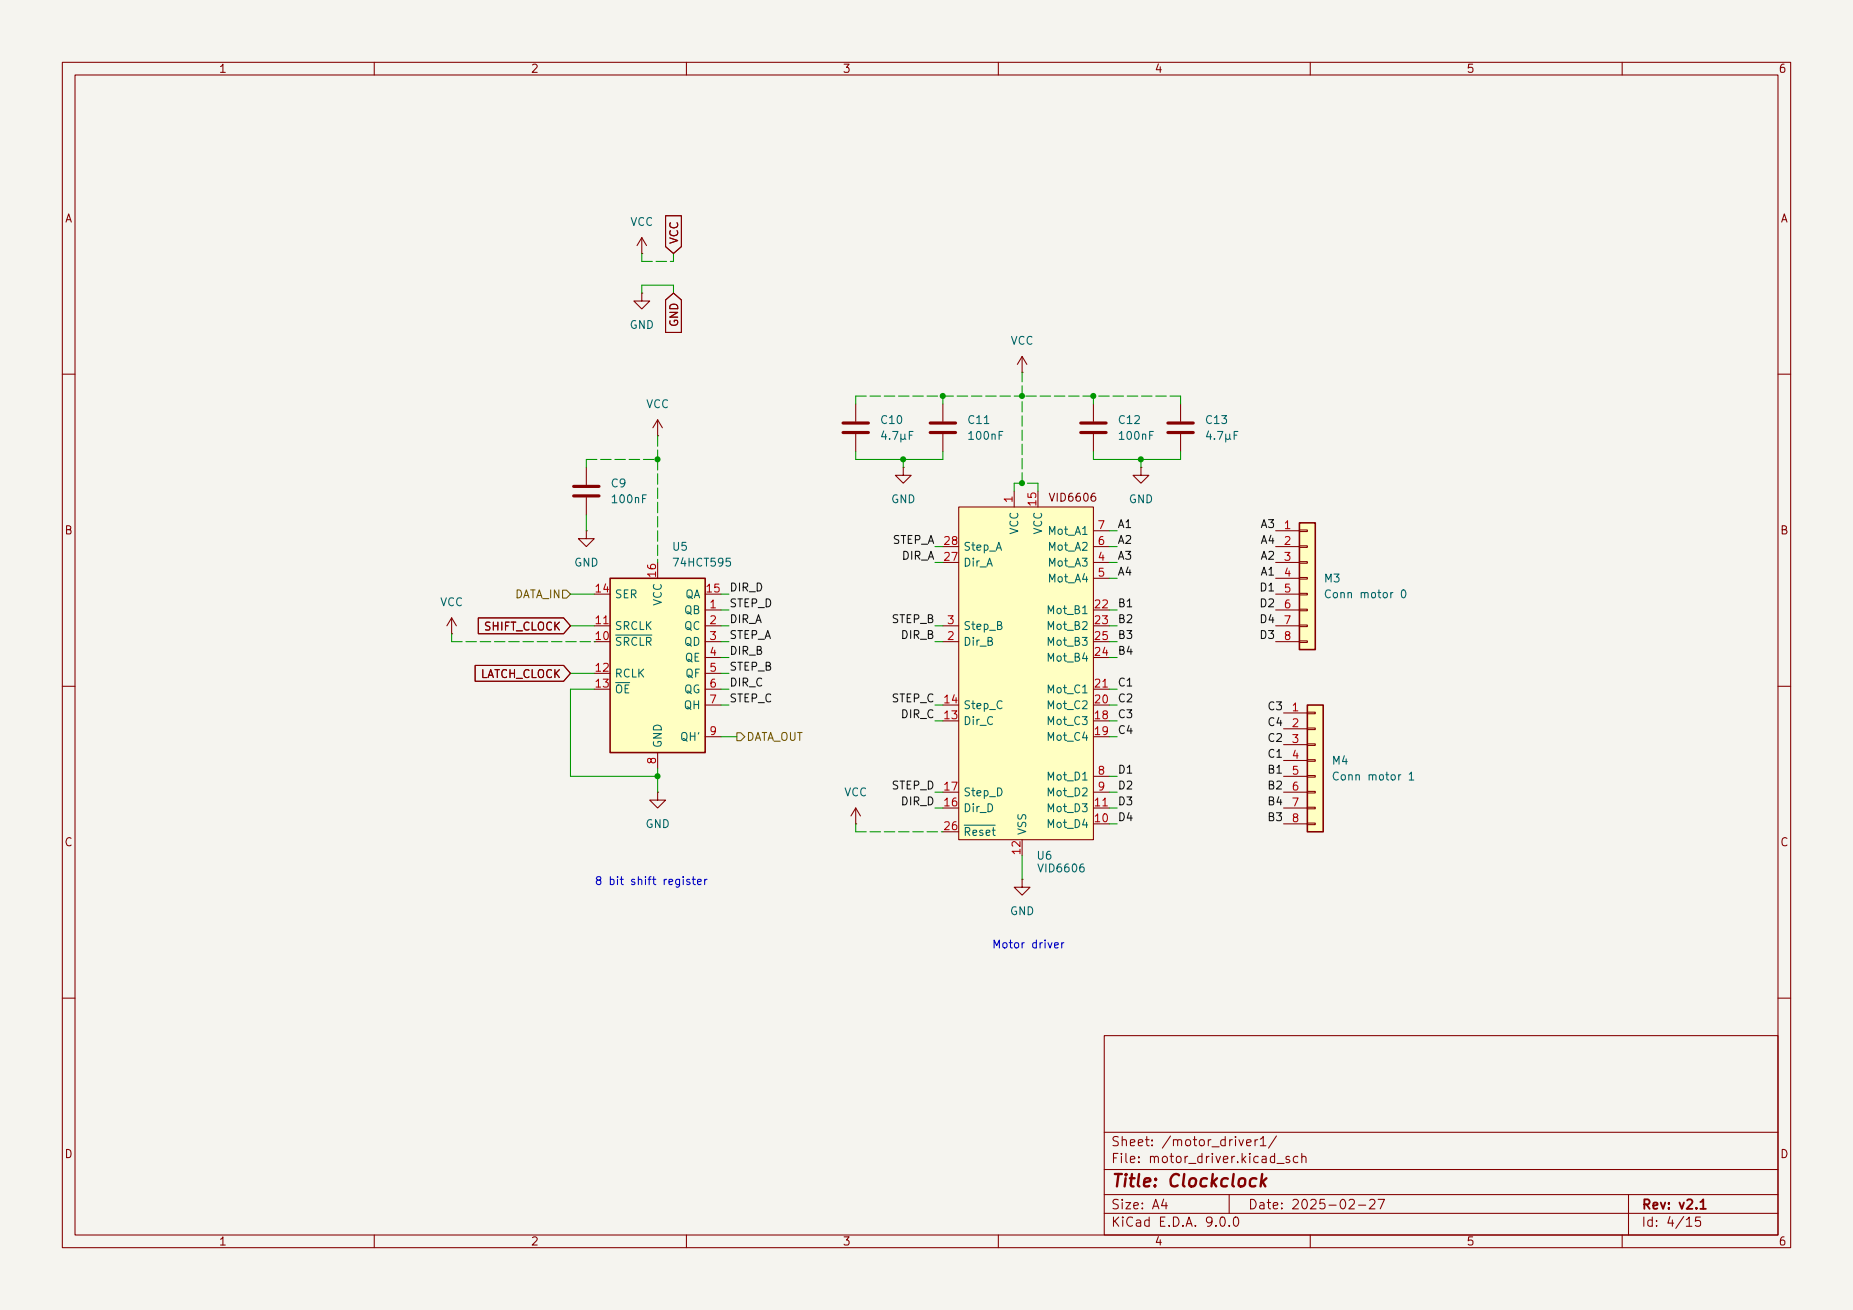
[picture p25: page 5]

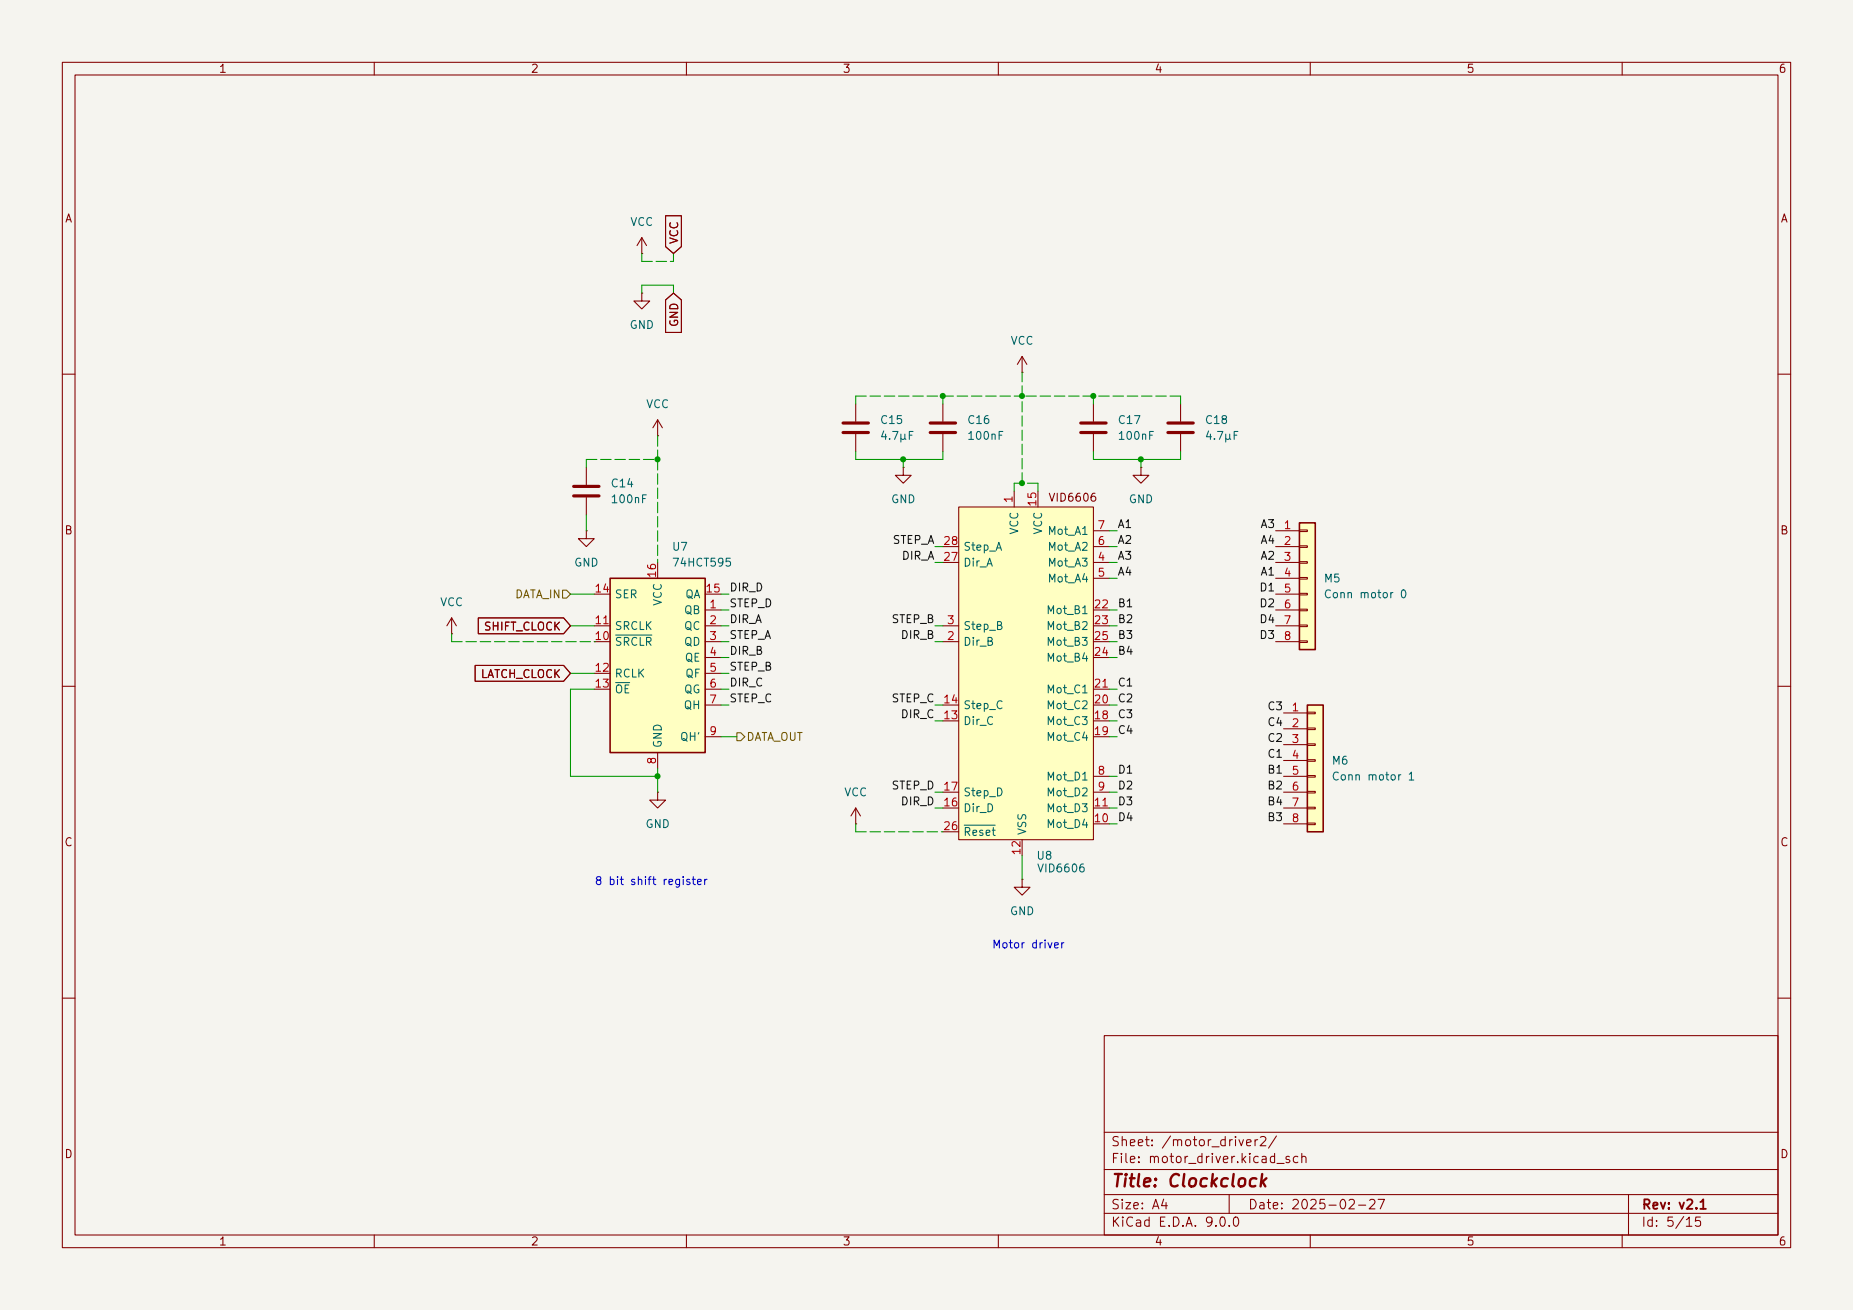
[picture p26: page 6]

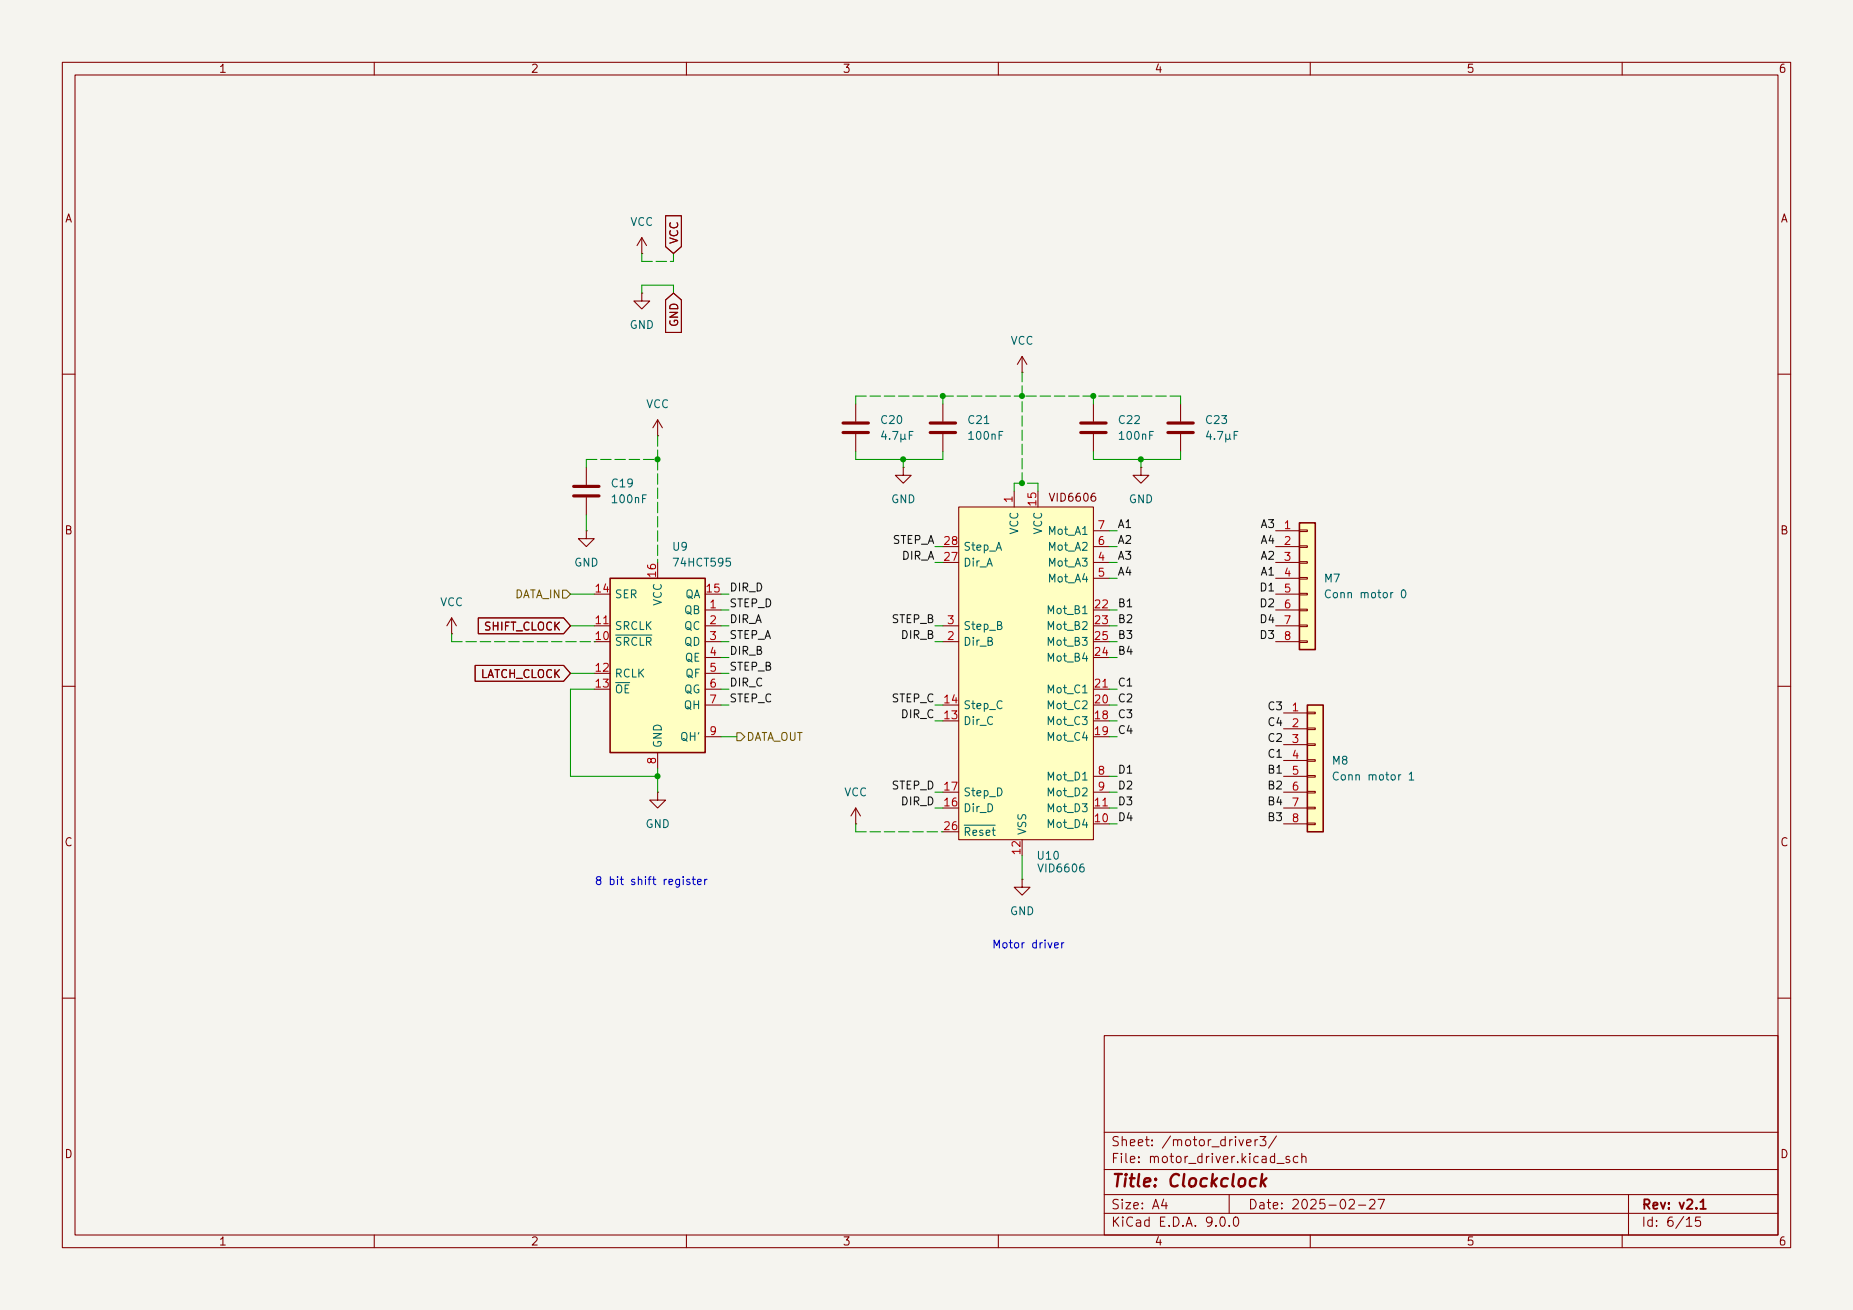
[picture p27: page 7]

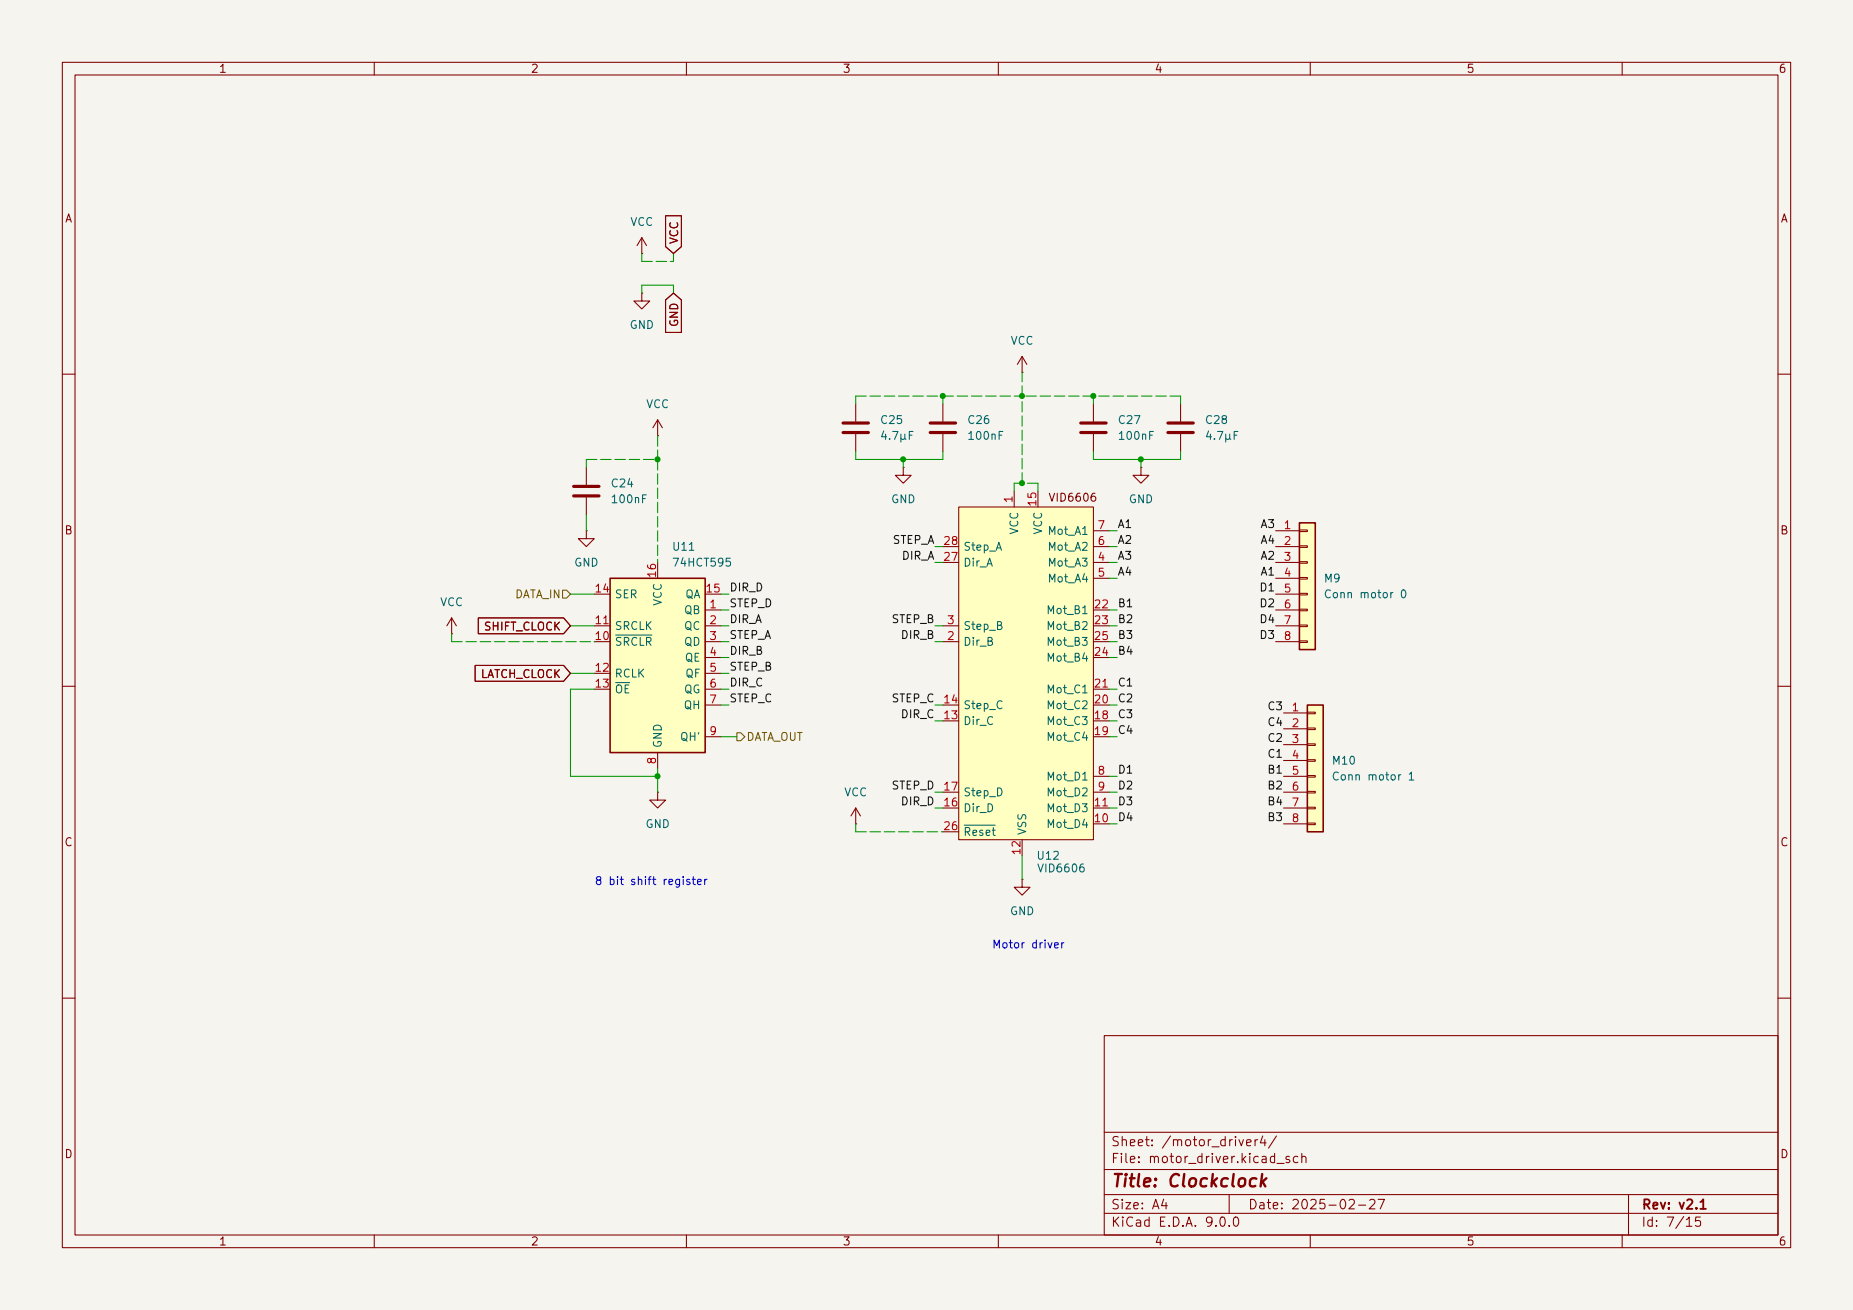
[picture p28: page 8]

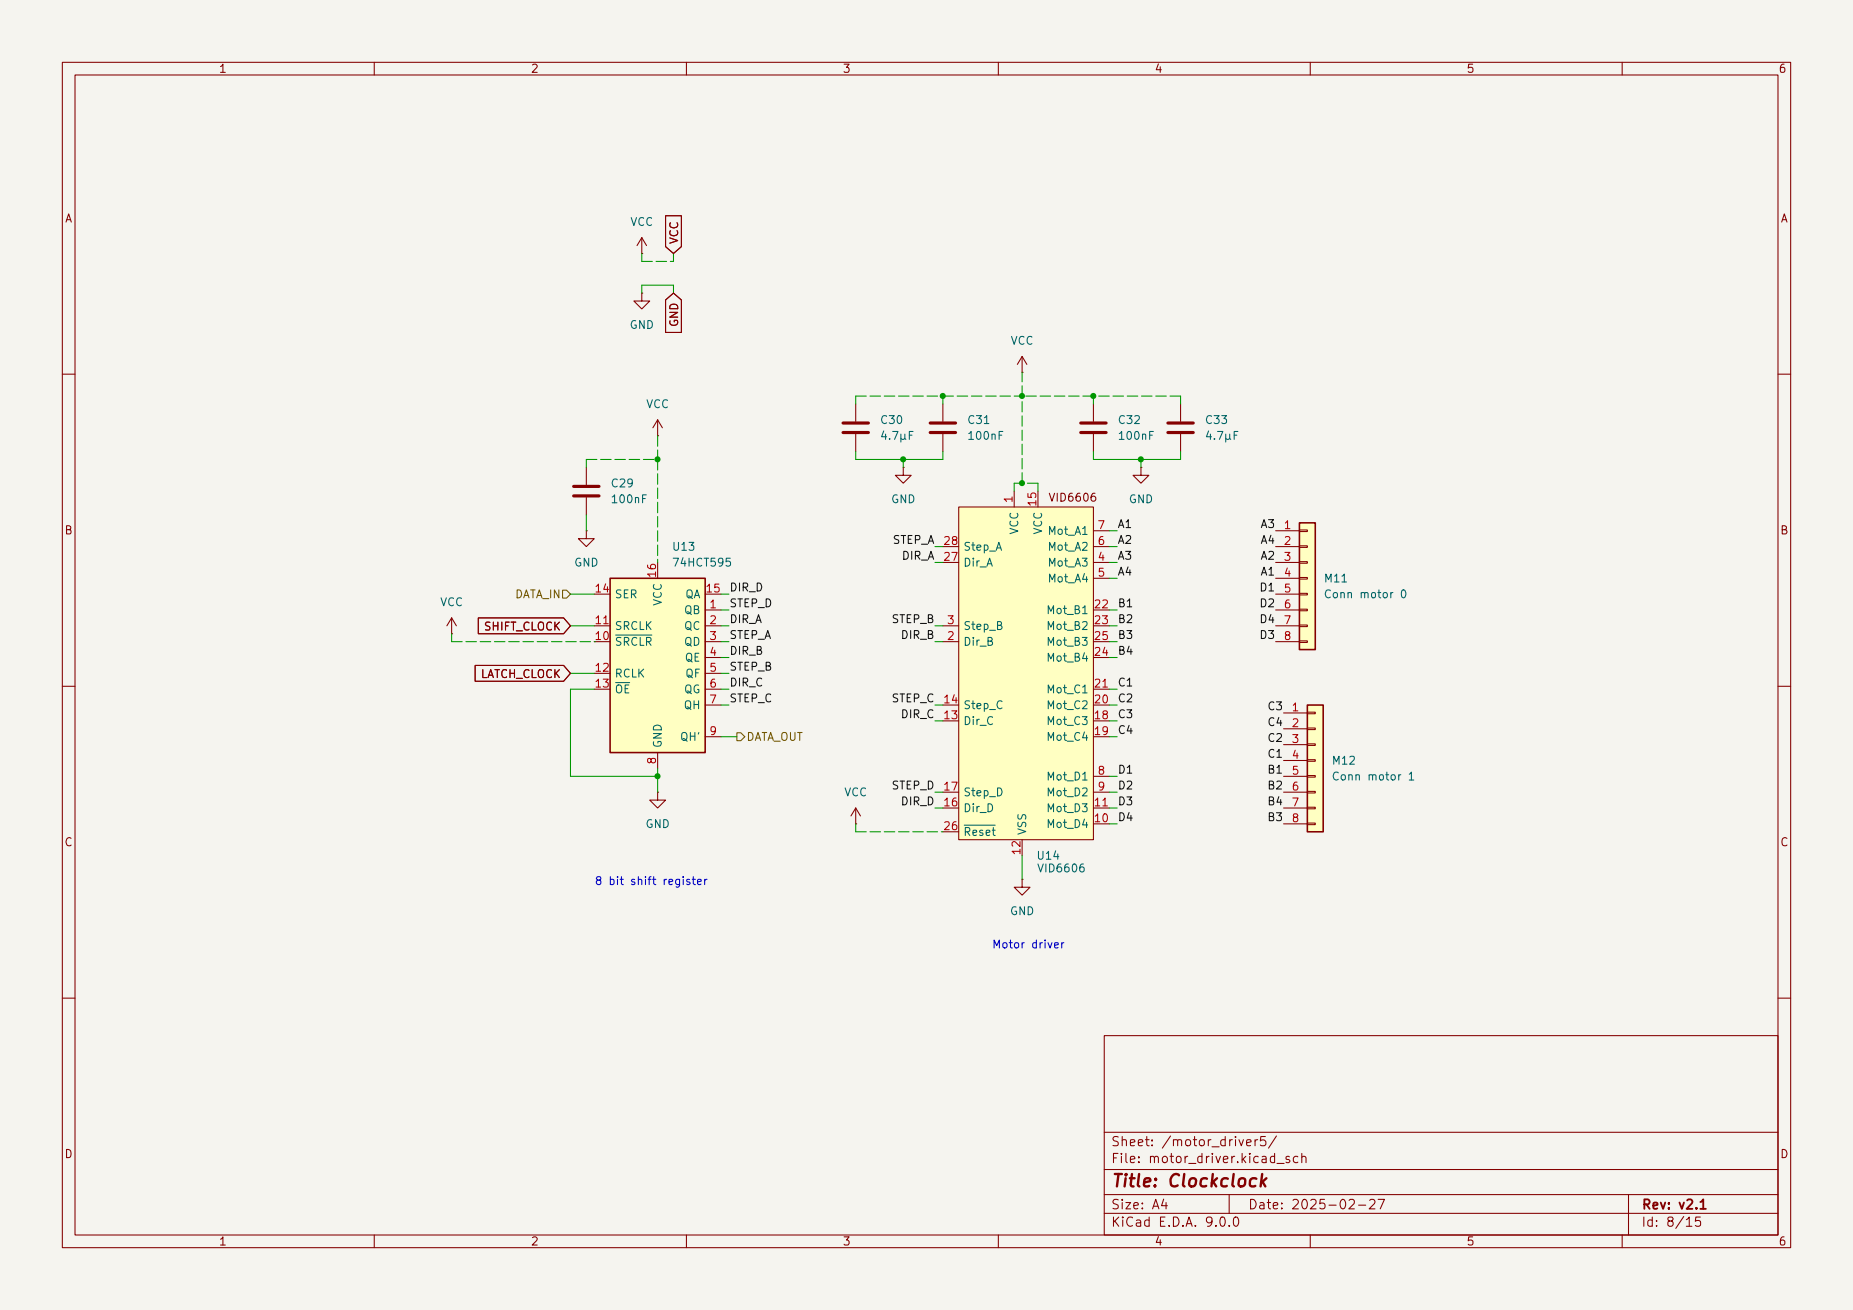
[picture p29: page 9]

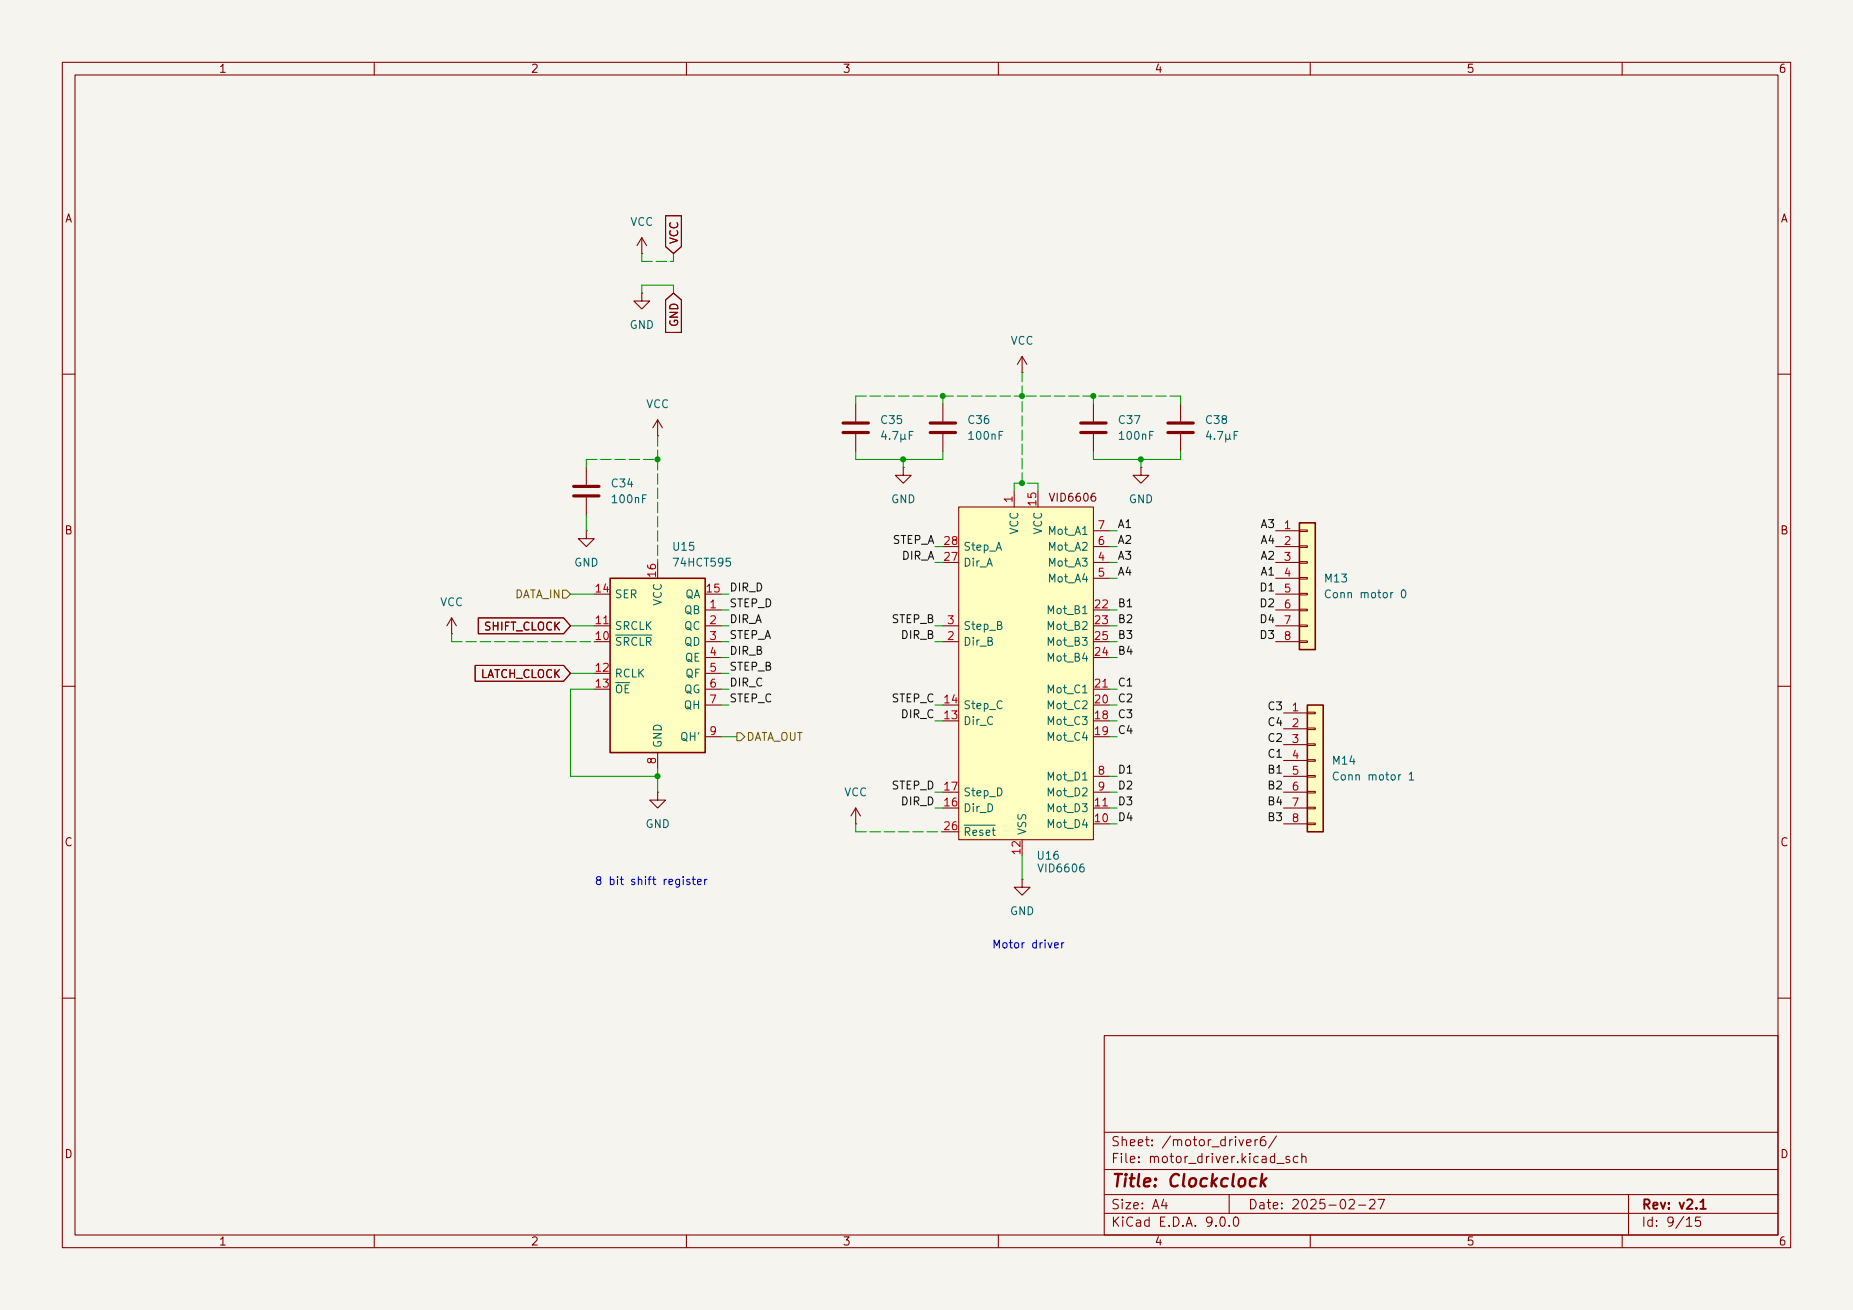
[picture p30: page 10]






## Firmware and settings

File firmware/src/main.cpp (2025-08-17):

#include <Arduino.h>

#include "animation/animation_manager.hpp"
#include "button/button.hpp"
#include "mode/mode.hpp"
#include "motor/motor_motion.h"
#include "motor/shift_register.h"
#include "time_manager.hpp"

#ifdef NTP_WIFI_SYNC
#include "ntp_sync.hpp"
#endif

void setup()
{
#ifdef DEBUG
	Serial.begin(115200);
	Serial.println("start");
#endif /* Debug */
	shift_reg_init();
	rtc_init();
	button_init();
	motor_init();

	// Initialize animation system
	AnimationManager::getInstance().init();

	// Configure DST for Central European Time (CET/CEST)
	set_dst_timezone(true, 1, 2); // Winter: UTC+1, Summer: UTC+2

#ifdef NTP_WIFI_SYNC
	// Note: NTP sync should use UTC time, DST will be applied automatically
	SyncResult result = sync_rtc_once("SSID", "PASSWORD", TimeZone::UTC);
	if (result == SyncResult::SUCCESS) {
		Serial.println("RTC synchronized successfully!");
	} else {
		Serial.println("RTC sync failed!");
	}
#endif

#if 0
	ctrl_test();
#endif

#if 0
	unsigned long last_time_ms = 0;

	int motor_id = 0;
	while (true) {
		const unsigned long time_ms = millis();

		if (time_ms > last_time_ms && time_ms - last_time_ms >= 1000) {
			last_time_ms = time_ms;
			motor_test(motor_id);
			Serial.print("Loop ");
			Serial.println(motor_id);
			motor_id++;
			if (motor_id >= NUM_MOTORS) {
				motor_id = 0;
			}
		}

		motor_loop();
	}
#endif
	display_time();
#ifdef DEBUG
	Serial.println("Start!");
#endif /* Debug */
}

void loop()
{
#if 0
	const unsigned long time_us_0 = micros();
#endif /* 0 */

	loop_buttons();
	loop_mode();

	motor_loop();

#if 0
	const unsigned long time_us_1 = micros();
	Serial.print("Loop timing (us): ");
	Serial.println(time_us_1 - time_us_0);
#endif /* 0 */
}

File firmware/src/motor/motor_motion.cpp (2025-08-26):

#include "motor_motion.h"
#include "AccelStepper.h"
#include "cfg.hpp"
#include "shift_register.h"

#ifdef DEBUG_MOTION
#define DBG_MOTOR_MOTION(...)    Serial.print(__VA_ARGS__)
#define DBG_MOTOR_MOTION_LN(...) Serial.println(__VA_ARGS__)
#else
#define DBG_MOTOR_MOTION(...)
#define DBG_MOTOR_MOTION_LN(...)
#endif

// Constants replacing magic numbers
static constexpr uint8_t STEP_MASK = 0b11;
static constexpr uint8_t DIRECTION_MASK = 0b01010101;
static constexpr uint8_t STEP_BIT = 0b10;
static constexpr uint8_t DIRECTION_BIT_EVEN = 0b01;
static constexpr uint8_t DIRECTION_BIT_ODD = 0b00;
static constexpr uint8_t SEQUENCE_BITS_PER_MOTOR = 2;
static constexpr int MOTOR_MAPPING_ERROR = -1;
static constexpr int MOTORS_PER_BLOCK = 4;
static constexpr int DRIVERS_PER_PAIR = 2;

static constexpr int MOTOR_MAX_SPEED = 1000;
static constexpr int MOTOR_ACC = 100;

static constexpr struct {
	uint32_t acceleration;
	uint32_t speed;
} motor_config_ = {.acceleration = MOTOR_ACC, .speed = MOTOR_MAX_SPEED};

static std::array<uint8_t, SHIFT_REG_SIZE> steps_ = {};

enum {
	MOTOR_A,
	MOTOR_B,
	MOTOR_C,
	MOTOR_D,
};

// Define driver and motor IDs with more descriptive names
enum DriverId : uint8_t {
	M1,
	M2,
	M3,
	M4,
	M5,
	M6,
	M7,
	M8,
	M9,
	M10,
	M11,
	M12,
	M13,
	M14,
	M15,
	M16,
	M17,
	M18,
	M19,
	M20,
	M21,
	M22,
	M23,
	M24,
};

enum MotorId : uint8_t {
	MOTOR_0,
	MOTOR_1,
	MOTOR_2,
	MOTOR_3,
	MOTOR_4,
	MOTOR_5,
	MOTOR_6,
	MOTOR_7,
	MOTOR_8,
	MOTOR_9,
	MOTOR_10,
	MOTOR_11,
	MOTOR_12,
	MOTOR_13,
	MOTOR_14,
	MOTOR_15,
	MOTOR_16,
	MOTOR_17,
	MOTOR_18,
	MOTOR_19,
	MOTOR_20,
	MOTOR_21,
	MOTOR_22,
	MOTOR_23,
	MOTOR_24,
	MOTOR_25,
	MOTOR_26,
	MOTOR_27,
	MOTOR_28,
	MOTOR_29,
	MOTOR_30,
	MOTOR_31,
	MOTOR_32,
	MOTOR_33,
	MOTOR_34,
	MOTOR_35,
	MOTOR_36,
	MOTOR_37,
	MOTOR_38,
	MOTOR_39,
	MOTOR_40,
	MOTOR_41,
	MOTOR_42,
	MOTOR_43,
	MOTOR_44,
	MOTOR_45,
	MOTOR_46,
	MOTOR_47,
};

/**
 * @brief Maps a logical motor and driver combination to a physical motor index.
 *
 * The mapping logic is based on a regular pattern:
 * - Drivers are grouped in pairs: (M1, M2), (M3, M4), ..., (M23, M24).
 * - Each pair corresponds to a 4-slot block of physical motor indices.
 * - These blocks are ordered in descending order starting from (NUM_MOTORS - 4).
 * - For each pair:
 *   - The first driver in the pair maps to the first two slots in the block:
 *       even (lower) motors → offset 0 (D), odd (upper) motors → offset 1 (A)
 *   - The second driver in the pair maps to the next two slots:
 *       even → offset 2 (C), odd → offset 3 (B)
 *
 * @param motor The motor ID (even = lower, odd = upper).
 * @param driver The driver to which the motor is assigned (M1–M24).
 * @return The corresponding physical motor index, or MAP_ERROR if invalid.
 */
static constexpr int mapMotorToPhysical(const MotorId motor, const DriverId driver)
{
	if (driver > M24) {
		return MOTOR_MAPPING_ERROR;
	}

	const bool is_lower_motor = motor % 2 == 0;
	const int driver_index = driver;
	const int block = driver_index / DRIVERS_PER_PAIR;
	const int block_base = (NUM_MOTORS - MOTORS_PER_BLOCK) - (block * MOTORS_PER_BLOCK);

	const bool is_first_driver_in_pair = (driver_index % DRIVERS_PER_PAIR == 0);

	if (is_first_driver_in_pair) {
		return block_base + (is_lower_motor ? 0 : 1); // D or A
	} else {
		return block_base + (is_lower_motor ? 2 : 3); // C or B
	}
}


// Test of the mapping function
static_assert(mapMotorToPhysical(MOTOR_0, M1) == MOTOR_44);
static_assert(mapMotorToPhysical(MOTOR_1, M1) == MOTOR_45);
static_assert(mapMotorToPhysical(MOTOR_2, M2) == MOTOR_46);
static_assert(mapMotorToPhysical(MOTOR_3, M2) == MOTOR_47);
static_assert(mapMotorToPhysical(MOTOR_30, M23) == MOTOR_0);
static_assert(mapMotorToPhysical(MOTOR_31, M23) == MOTOR_1);
static_assert(mapMotorToPhysical(MOTOR_30, M24) == MOTOR_2);
static_assert(mapMotorToPhysical(MOTOR_31, M24) == MOTOR_3);

constexpr std::array<DriverId, NUM_MOTORS> MOTOR_DRIVER_ASSIGNMENT = []() {
	std::array<DriverId, NUM_MOTORS> arr{};
	// Digit 1
	arr.at(47) = M14;
	arr.at(46) = M14;
	arr.at(45) = M12;
	arr.at(44) = M12;
	arr.at(43) = M13;
	arr.at(42) = M13;
	arr.at(41) = M11;
	arr.at(40) = M11;
	arr.at(39) = M15;
	arr.at(38) = M15;
	arr.at(37) = M10;
	arr.at(36) = M10;

	// Digit 2
	arr.at(35) = M9;
	arr.at(34) = M9;
	arr.at(33) = M16;
	arr.at(32) = M16;
	arr.at(31) = M8;
	arr.at(30) = M8;
	arr.at(29) = M17;
	arr.at(28) = M17;
	arr.at(27) = M7;
	arr.at(26) = M7;
	arr.at(25) = M18;
	arr.at(24) = M18;

	// Digit 3
	arr.at(23) = M6;
	arr.at(22) = M6;
	arr.at(21) = M19;
	arr.at(20) = M19;
	arr.at(19) = M5;
	arr.at(18) = M5;
	arr.at(17) = M3;
	arr.at(16) = M3;
	arr.at(15) = M21;
	arr.at(14) = M21;
	arr.at(13) = M20;
	arr.at(12) = M20;

	// Digit 4
	arr.at(11) = M22;
	arr.at(10) = M22;
	arr.at(9) = M2;
	arr.at(8) = M2;
	arr.at(7) = M4;
	arr.at(6) = M4;
	arr.at(5) = M1;
	arr.at(4) = M1;
	arr.at(3) = M24;
	arr.at(2) = M24;
	arr.at(1) = M23;
	arr.at(0) = M23;

	return arr;
}();

constexpr std::array<int, NUM_MOTORS> MOTOR_MAPPING = []() {
	std::array<int, NUM_MOTORS> arr{};
	for (int i = 0; i < NUM_MOTORS; ++i) {
		arr[i] = mapMotorToPhysical(static_cast<MotorId>(i), MOTOR_DRIVER_ASSIGNMENT[i]);
	}
	return arr;
}();

static void set_motor_bits_(int motor_id, const int sequence)
{
	/* 74HCT595 output is:
	 * QA: DIR_D
	 * QB: STEP_D
	 * QC: DIR_A
	 * QD: STEP_A
	 * QE: DIR_B
	 * QF: STEP_B
	 * QG: DIR_D
	 * QH: STEP_C
	 *
	 * SPI is configured as MSB first
	 * */
	motor_id = static_cast<int>(MOTOR_MAPPING.at(motor_id));
	if (motor_id < 0 || motor_id >= NUM_MOTORS) {
		return;
	}
	const int motor_num = motor_id % NUM_MOTORS_PER_SHIFT_REG;
	steps_.at(motor_id / NUM_MOTORS_PER_SHIFT_REG) &=
	    ~(STEP_MASK << (motor_num * SEQUENCE_BITS_PER_MOTOR));
	steps_.at(motor_id / NUM_MOTORS_PER_SHIFT_REG) |= sequence << (motor_num * SEQUENCE_BITS_PER_MOTOR);
}

static void update_direction_()
{
	auto steps = steps_;
	for (auto &step : steps) {
		/* Mask the step instruction, only keep the direction which is the first bit */
		step &= DIRECTION_MASK;
	}
	ctrl_motors(steps);
}

static void reset_position_()
{
	for (auto &step : steps_) {
		step &= DIRECTION_MASK;
	}
	ctrl_motors(steps_);
}

Motor::Motor()
    : AccelStepper(AccelStepper::DRIVER)
{
	setMaxSpeed(motor_config_.speed);
	setAcceleration(motor_config_.acceleration);
};

void Motor::step1(const long)
{
	uint8_t sequence = 0b00;

	/* Set-up direction, this is the first bit */
	if (_motor_id % 2 == 0) {
		sequence = _direction ? DIRECTION_BIT_EVEN : 0b00;
	} else {
		sequence = _direction ? 0b00 : DIRECTION_BIT_EVEN;
	}

	if (isRunning()) {
		/* Update the step bit, this is the second bit */
		sequence |= STEP_BIT;
	}

	set_motor_bits_(_motor_id, sequence);
}

void Motor::setMotorId(uint8_t motor_id)
{
	_motor_id = motor_id;
}

void Motor::enableOutputs()
{
	/* Nothing to do */
}
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

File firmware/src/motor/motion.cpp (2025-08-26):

#include "Arduino.h"

#include "cfg.hpp"
#include "motion.hpp"

#include "motor_helper.h"
#include "motor_motion.h"

#ifdef DEBUG_MOTION
#define DBG_MOTION(...)    Serial.print(__VA_ARGS__)
#define DBG_MOTION_LN(...) Serial.println(__VA_ARGS__)
#else
#define DBG_MOTION(...)
#define DBG_MOTION_LN(...)
#endif

// Constants replacing magic numbers
static constexpr uint32_t MAX_ANGLE_VALUE = 359;
static constexpr int SEQUENCE_LENGTH = 24; // M-S Quad Driver X12.017 has 24 steps
static constexpr int DECIMAL_BASE = 10;
static constexpr int MAX_HOURS = 99;
static constexpr int MAX_MINUTES = 99;

typedef uint16_t pos_t;

enum transition_t : uint8_t {
	TRANS_SHORTER_PATH,
	TRANS_CLOCKWISE,
};

/******************************************************************************************************************/

/**
 * Digits
 * structure: {
 * h0, m0,
 * h1, m1,
 * ...
 * h5, m5
 * }
 */

static constexpr int NUM_MOTOR_PER_DIAL = 2;
static constexpr int NUM_DIAL_PER_DIGIT = 6;
static constexpr int NUM_DIGIT = 4;

typedef uint16_t angle_t;

struct clock_dial_t {
	angle_t angle_absolute[NUM_MOTOR_PER_DIAL];
};

struct clock_digit_t {
	clock_dial_t clocks[NUM_DIAL_PER_DIGIT];
};

struct full_clock_t {
	clock_digit_t digit[NUM_DIGIT];
};

static constexpr struct {
	transition_t transition;
} _ctx = {.transition = TRANS_CLOCKWISE};

static constexpr clock_digit_t digit_0 = {
    .clocks = {{90, 180}, {0, 180}, {0, 90}, {180, 270}, {0, 180}, {270, 0}}};

static constexpr clock_digit_t digit_1 = {
    .clocks = {{225, 225}, {225, 225}, {225, 225}, {180, 180}, {0, 180}, {0, 0}}};

static constexpr clock_digit_t digit_2 = {
    .clocks = {{90, 90}, {90, 180}, {90, 0}, {270, 180}, {0, 270}, {270, 270}}};

static constexpr clock_digit_t digit_3 = {
    .clocks = {{90, 90}, {90, 90}, {90, 90}, {270, 180}, {180, 0}, {270, 0}}};

static constexpr clock_digit_t digit_4 = {
    .clocks = {{180, 180}, {0, 90}, {225, 225}, {180, 180}, {0, 180}, {0, 0}}};

static constexpr clock_digit_t digit_5 = {
    .clocks = {{90, 180}, {0, 90}, {90, 90}, {270, 270}, {180, 270}, {270, 0}}};

static constexpr clock_digit_t digit_6 = {
    .clocks = {{180, 180}, {0, 180}, {0, 90}, {45, 45}, {270, 180}, {0, 270}}};

static constexpr clock_digit_t digit_7 = {
    .clocks = {{90, 90}, {225, 225}, {225, 225}, {270, 180}, {0, 180}, {0, 0}}};

static constexpr clock_digit_t digit_8 = {
    .clocks = {{90, 180}, {90, 180}, {0, 90}, {270, 180}, {270, 180}, {0, 270}}};

static constexpr clock_digit_t digit_9 = {
    .clocks = {{90, 180}, {0, 90}, {225, 225}, {180, 270}, {0, 180}, {0, 0}}};

static constexpr clock_digit_t _digits[10] = {
    digit_0, digit_1, digit_2, digit_3, digit_4, digit_5, digit_6, digit_7, digit_8, digit_9};

static full_clock_t _get_clock_state_from_time(const int h, const int m)
{
	DBG_MOTION("Set time: ");
	DBG_MOTION(h);
	DBG_MOTION(":");
	DBG_MOTION_LN(m);

	const int d0 = h / DECIMAL_BASE;
	const int d1 = h - d0 * DECIMAL_BASE;
	const int d2 = m / DECIMAL_BASE;
	const int d3 = m - d2 * DECIMAL_BASE;

	const full_clock_t clock_state = {_digits[d0], _digits[d1], _digits[d2], _digits[d3]};
	return clock_state;
}

static void _shortest_path(const int motor_idx, const pos_t target_pos_absolute)
{
	long cur_position = motor_get_position(motor_idx);
	if (target_pos_absolute == cur_position) {
		/* Already at the correct position */
		return;
	}

	/* Sanitize position in case it is running multiple turns */
	if (cur_position < 0) {
		cur_position *= -1;
	}
	cur_position %= NUM_STEPS_PER_ROT;

	/* Check the shortest path */
	int clockwise;
	int counterclockwise;
	if (cur_position > target_pos_absolute) {
		clockwise = NUM_STEPS_PER_ROT - (cur_position - target_pos_absolute);
		counterclockwise = cur_position - target_pos_absolute;
	} else {
		clockwise = target_pos_absolute - cur_position;
		counterclockwise = NUM_STEPS_PER_ROT - (target_pos_absolute - cur_position);
	}

	if (clockwise > counterclockwise) {
		motor_move_to_relative(motor_idx, counterclockwise * -1);
	} else {
		motor_move_to_relative(motor_idx, clockwise);
	}


#if 0
	DBG_MOTION("Target position: ");
	DBG_MOTION(target_pos);
	DBG_MOTION("/");
	DBG_MOTION_LN(cur_position);
#endif
}

static void _clockwise_path(const int motor_idx, const pos_t target_pos_absolute)
{
	long cur_position = motor_get_position(motor_idx);

	if (target_pos_absolute == cur_position) {
		/* Already at the correct position */
		return;
	}

	/* Sanitize position in case it is running multiple turns */
	if (cur_position < 0) {
		cur_position *= -1;
	}
	cur_position %= NUM_STEPS_PER_ROT;

	if (target_pos_absolute > cur_position) {
		motor_move_to_relative(motor_idx, target_pos_absolute - cur_position);
	} else {
		motor_move_to_relative(motor_idx, NUM_STEPS_PER_ROT - cur_position + target_pos_absolute);
	}
}

static angle_t _sanitize_angle(angle_t angle)
{
	if (angle > MAX_ANGLE_VALUE) {
		angle = MAX_ANGLE_VALUE;
	}
	return angle;
}

static pos_t _adjust_pos(pos_t pos)
{
	/* Adjusts the target step to always arrive at the first motor step sequence */
	const pos_t modulo = pos % SEQUENCE_LENGTH == 0 ? 0 : SEQUENCE_LENGTH - pos % SEQUENCE_LENGTH;
	pos += modulo;
	pos %= NUM_STEPS_PER_ROT;

	return pos;
}

static void _update_motor_pos(const int motor_idx, angle_t angle_absolute)
{
#if 0
	DBG_MOTION("Motor: ");
	DBG_MOTION(motor_idx);
	DBG_MOTION(", angle: ");
	DBG_MOTION_LN(angle);
#endif

	angle_absolute = _sanitize_angle(angle_absolute);
	pos_t target_pos_absolute = angleToSteps(angle_absolute);
	target_pos_absolute = _adjust_pos(target_pos_absolute);

	if constexpr (TRANS_SHORTER_PATH == _ctx.transition) {
		_shortest_path(motor_idx, target_pos_absolute);
	} else if constexpr (TRANS_CLOCKWISE == _ctx.transition) {
		_clockwise_path(motor_idx, target_pos_absolute);
	}
}

static void _update_dial(const int digit_idx, const int dial_idx, const clock_dial_t *clock_dial)
{
	for (int motor_idx = 0; motor_idx < NUM_MOTOR_PER_DIAL; motor_idx++) {
		const int motor_id = digit_idx * NUM_DIAL_PER_DIGIT * NUM_MOTOR_PER_DIAL +
		                     dial_idx * NUM_MOTOR_PER_DIAL + motor_idx;
		_update_motor_pos(motor_id, clock_dial->angle_absolute[motor_idx]);
#if 0
		DBG_MOTION(motor_id);
		DBG_MOTION(": ");
		DBG_MOTION(clock_dial->angle_absolute[motor_idx]);
		DBG_MOTION_LN();
#endif
	}
}

static void _update_digits(const int digit_idx, const struct clock_digit_t *clock_digit)
{
	for (int dial_idx = 0; dial_idx < NUM_DIAL_PER_DIGIT; dial_idx++) {
		_update_dial(digit_idx, dial_idx, &clock_digit->clocks[dial_idx]);
	}
}

static void _update_clock(const full_clock_t *full_clock)
{
	for (int digit_idx = 0; digit_idx < NUM_DIGIT; digit_idx++) {
		_update_digits(digit_idx, &full_clock->digit[digit_idx]);
	}
}
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

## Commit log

2024-08-13 [animation] New strategies for moving motors
2024-08-14 [shift_register] Speed-up pin toggling
    digitalWrite was too slow, remove unnecessary instructions from
    this function
2024-08-14 [shift_register] Fix array of PWM
    Now there is one byte for 1 motor.
    It takes more memory but it's faster.
2024-08-14 [animation] Fix motor position adjustment
2024-08-14 [animation] Init motor delay in specific function
2024-08-18 [button] Add first button implementation
2024-08-18 Add button logic to enter in different mode
2024-08-19 [animation] Handle motor acceleration in every loop
2024-08-19 [shift_reg] Add TODO to implement SPI solution
2024-08-19 [motor] Rename motors related files
2024-08-19 [motor] Rename motor loop function
2024-08-19 [calib] Create calib mode in the motion driver
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2024-08-20 [calib] Set motors to position 0 when entering the calib mode
2024-08-20 [shift_reg] Use SPI module to transmit data to the shift register
2024-08-20 [mode] Add shutdown mode
    When the clock is powered off, it's very useful to
    set needles at neutral position to avoid calibration
    on next boot
    [mode.cpp, motor_motion.cpp]
2024-08-20 [button] Fix corner case in button detection
    [button.cpp]
2024-08-21 [button] Configure button pull-up in software
    Workaround while no hardware is connected yet
    [button.cpp]
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2024-08-21 [button] Fix button get state
    [button.cpp]
2024-08-21 [button] Reset encoder after count is fetched
    [button.cpp]
2024-08-21 [calib] Reset encoder count during init
    [calibration.cpp, mode.cpp]
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2024-08-21 [shift_reg] Fix step buffer corruption
    Arduino SPI library writes MISO into the input buffer. So we need another buffer
    to send the data.
    [cfg.hpp, motor_motion.cpp, shift_register.cpp]
2024-08-21 [motion] Fix motor bit manipulation
    [motor_motion.cpp]
2024-08-21 [motion] Fix motor not being disabled
    _check_delay also checked if motor had remaining steps.
    So, the function that is updating the step pattern could not deactivate the motor.
    [motor_motion.cpp]
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2024-08-22 [button] Reset encoder count in button reset
    [button.cpp]
2024-08-22 [calib] Remove duplicated code
    The encoder is reset in button_reset already
    [calibration.cpp]
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2024-11-07 [motion] Update step sequence
    Use the real one which requires more power
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2024-11-09 [button] Remove internal pullup
    Replaced with external pullup
    [button.cpp]
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2024-11-11 [mode] Rename enum to fix compile with new board
    [mode.cpp]
2024-11-11 [platformio] Add new board
    The lib AccelStepper will be included and this lib takes a lot of RAM.
    Arduino Uno does not have enough to support it.
    Switch to Espressif ESP32-C3 MCU
2024-11-11 [motor] Use driver AccelStepper
    Implement the motor motion with driver of David Austin
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2024-11-12 [calib] Fix calib increment
    [calibration.cpp]
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2024-11-12 [motor] Fix half step sequence
    [motor_motion.cpp]
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2024-11-22 [motion] Add missing include
    [motion.cpp]
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2024-11-22 [AccelStepper] Disable step motor when not running
    Make sure that the last step is done before shutting it done.
    Magic value 50000µs is arbitrary, to be improved.
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2024-11-22 First Kicad commit
    [control_board.kicad_sch, driver_board.kicad_pcb, driver_board.kicad_sch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]
2024-11-23 [elec] New design with BKA30D-R5
    [control_board.kicad_sch, driver_board.kicad_pcb, driver_board.kicad_sch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]
2024-11-24 [elec] Add BKA30D-R5 symbol
    [motor_board.kicad_pcb, motor_board.kicad_sch]
2024-11-25 [elec] continue routing
    [control_board.kicad_sch, driver_board.kicad_pcb, driver_board.kicad_sch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]
2024-11-26 [elec] First version of the routing of driver board
    [control_board.kicad_sch, driver_board.kicad_pcb, motor_driver.kicad_sch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]
2024-11-27 [elec] Add space for physical button
    [control_board.kicad_sch, driver_board.kicad_pcb, motor_driver.kicad_sch]
2024-11-27 [elec] Add one more hall sensor
    [motor_board.kicad_pcb, motor_board.kicad_sch]
2025-01-11 Update BKA30D-R5 dimensions
    Also add some silkscreen on both PCB
    [control_board.kicad_sch, driver_board.kicad_pcb, driver_board.kicad_sch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]
2025-01-15 Update schematic with VID6606
    Use the 'official' driver of VID28-05 motors.
    Put back the 74HCT595 bit shift register to link all
    motor drivers.
    Work in progress.
    [control_board.kicad_sch, driver_board.kicad_pcb, driver_board.kicad_sch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]
2025-01-18 New schematic + route
    The new design schematic is done.
    Route is ongoing
    [control_board.kicad_sch, driver_board.kicad_pcb, motor_driver.kicad_sch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]
2025-01-26 PCB done, ready to be ordered
    [control_board.kicad_sch, driver_board.kicad_pcb, driver_board.kicad_sch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]
2025-02-26 Update footprint of the level shifter
    [control_board.kicad_sch, driver_board.kicad_pcb, driver_board.kicad_sch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]
2025-02-26 Various updates
    Reposition rotary encoder
    reposition RTC
    add GND pads
    update footprint of the big capa
    [driver_board.kicad_pcb, power_supply_mcu.kicad_sch]
2025-02-26 Update silkscreen
    [control_board.kicad_sch, driver_board.kicad_pcb, driver_board.kicad_sch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]
2025-02-26 Update symbols
    [control_board.kicad_sch, driver_board.kicad_pcb, power_supply_mcu.kicad_sch]
2025-02-26 Fix OE for the level shifter
    [control_board.kicad_sch, driver_board.kicad_pcb]
2025-02-26 Update page number
    [control_board.kicad_sch, driver_board.kicad_sch, motor_driver.kicad_sch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]
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2025-02-26 Update for kicad 9
    [motor_board.kicad_pcb, motor_board.kicad_sch]
2025-02-27 Update hole size
    [control_board.kicad_sch, driver_board.kicad_pcb]
2025-02-27 Create test PCB for stepper driver
    [test_board_motor_driver.kicad_pcb, test_board_motor_driver.kicad_sch]
2025-02-27 Finalize PCB order
    [control_board.kicad_sch, driver_board.kicad_pcb, driver_board.kicad_sch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]
2025-02-28 [motor] Implement the new stepper driver
    Now the bit shift register is connected to a new
    stepper driver: VID6606.
    There are 4 motors per bit shift register.
    The driver have two inputs per motor: direction and step.
2025-02-28 [elec] Update clockclock board PDF schematic
    Also remove old gerber.zip
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2025-02-28 [elec] Rename main board
    [clockclock_main.kicad_pcb, clockclock_main.kicad_sch, control_board.kicad_sch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]
2025-02-28 [elec] Rename stepper board
    [clokclock_stepper.kicad_pcb, clokclock_stepper.kicad_sch]
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2025-03-30 Fix typo
    [clockclock_main.kicad_sch, motor_driver.kicad_sch]
2025-04-01 Update number of steps per slot
    New steppers BKA30D-R5
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2025-05-11 Update digits patterns
    Adapt to main board v2.1
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2025-05-11 Invert direction for even motors
    Electric cables are not swapped, so, the direction
    needs to be swapped via software
    [motor_motion.cpp]
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2025-05-13 Map all motors
    Fake values right now, to be updated
2025-05-13 [elec] Update silkscreen for USB power
    [clockclock_main.kicad_pcb, clockclock_main.kicad_sch, control_board.kicad_sch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]
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2025-08-09 fix: correct time increment selection from hours to minutes
    [cfg_time.cpp]
2025-08-16 refactor: replace define with constexpr
    [motion.cpp, motor_motion.cpp]
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2025-08-17 fix: remove compile warning
    [animation_manager.cpp]
2025-08-26 feat: use encoder button as shutdown button
    This is more convenient with the current build.
2025-08-26 feat: improve wave animation
    Reduce speed of motors and move a column at the time.
2025-08-26 feat: improve sync animation
    Reduce speed of motors
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2025-08-26 feat: add bracket animation for hour change detection
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
